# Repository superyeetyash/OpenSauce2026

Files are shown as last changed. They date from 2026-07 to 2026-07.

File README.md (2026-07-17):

# Color Quackdown


An interactive arcade reaction game built for OpenSauce 2026 based on the prompt "Make something interactive." Duck Hunt Reaction Arcade is a modern take on the classic carnival duck shooting game. Instead of shooting ducks, players test their reflexes, accuracy, and color recognition by hitting the correct button before time runs out. The goal was to create a project that could be understood instantly by spectators, encourage repeated play, and combine mechanical design, electronics, and embedded programming into one interactive experience.

## Gameplay

The game uses six mechanical ducks arranged in two rows of three. Each duck is mounted on a servo-powered rack-and-pinion lift that allows it to rise from behind a wall. Every duck has a fixed color. In front of the player are six arcade buttons arranged in the same 2×3 layout, each containing an RGB LED. At the beginning of every round, the button colors are randomized. When a duck rises, the player must identify its color and press the matching illuminated button before the timer reaches zero. If the correct button is pressed, the duck lowers, a success sound plays, the score increases, and the next round begins with less time available. If the wrong button is pressed or time expires, the game ends. The timer progressively decreases after each successful round with a minimum limit of 1.5 seconds.

## Features

The project includes six servo-powered rising duck targets, RGB LED arcade buttons, color recognition gameplay, increasing difficulty, score tracking, high score storage, arcade-style sound effects, a HUB75 RGB LED matrix display, and fully physical controls designed for public interaction at events.

## System Architecture

The Arduino Mega 2560 is the main controller and handles all real-time game functions, including button inputs, RGB LED control, servo movement, game timing, sound effects, and score management. A Raspberry Pi Pico 2 is used as a dedicated display controller for the HUB75 LED matrix. Since HUB75 panels require constant high-speed refreshing, separating the display system from the gameplay controller keeps the game responsive. The Mega communicates with the Pico 2 over UART, sending information such as score, timer values, and game state.

## Bill of Materials (BOM)

| Quantity | Component | Purpose |
|---|---|---|
| 1 | Arduino Mega 2560 | Main game controller handling inputs, outputs, and game logic |
| 1 | Raspberry Pi Pico 2 | Dedicated HUB75 LED matrix display controller |
| 1 | P5 HUB75 64×32 RGB LED Matrix | Main arcade display for score, timer, and animations |
| 6 | MG90S metal gear micro servos | Drives the duck rack-and-pinion lifting mechanisms |
| 6 | 4-pin arcade buttons | Player input controls |
| 6 | Common cathode RGB LEDs | Button lighting system |
| 18 | 220Ω resistors | Current limiting for RGB LED channels |
| 1 | Passive speaker or buzzer | Arcade sound effects |
| 1 | 5V 10A power supply | Powers servos, LED matrix, and electronics |
| 1 | Power distribution block | Splits 5V power between system components |
| 1 | 470–1000µF electrolytic capacitor | Reduces servo voltage spikes |
| 1 | Servo wiring harness or jumper wires | Connects servo power and signals |
| 1 | Assorted jumper wires | General electrical connections |
| 1 | Breadboard or custom PCB | Prototyping and connecting electronics |
| 1 | 3D printed duck assemblies | Physical duck targets |
| 6 | Rack-and-pinion lift assemblies | Converts servo rotation into vertical duck movement |
| 1 | Laser-cut or fabricated enclosure | Houses the arcade system |

## Pin Configuration

The RGB LEDs use a common cathode configuration, with the common pin connected to ground and each RGB channel connected to the Arduino Mega through a 220Ω resistor. The arcade buttons use one signal connection and one ground connection with `INPUT_PULLUP`, meaning a pressed button reads as LOW. The current pin assignments are: pins 2–13 for RGB channels, pins 22–27 for additional RGB channels, pins 28–33 for buttons, and pin 34 for the speaker. The complete pin configuration is stored at the top of `ColorMatchGame/ColorMatchGame.ino`.

## Power System

The servos and HUB75 display should not be powered directly from the Arduino Mega's 5V pin. A dedicated 5V power supply is used to power the system through a distribution block, with separate rails for the servo system and LED matrix. The Arduino Mega, Raspberry Pi Pico 2, servo power, and display power all share a common ground. A 470–1000µF capacitor is placed near the servo power rail to reduce voltage drops caused by servo startup current spikes.

Estimated power requirements:

| Component | Estimated Current |
|---|---|
| Arduino Mega 2560 | ~200mA |
| Six MG90S servos | Up to 2A+ during movement |
| HUB75 LED matrix | 2–3A depending on brightness |
| RGB LEDs and logic | ~300mA |

## Repository Structure

The repository contains the main Arduino firmware in `ColorMatchGame/ColorMatchGame.ino` and the mechanical CAD files in the `cad/` folder. The firmware contains the complete game logic, button handling, RGB control, servo control, timing system, sound effects, and EEPROM high score storage. The CAD files include the duck models, rack-and-pinion lift system, servo mounts, and housing components. The mechanical design is created using parametric OpenSCAD models, allowing dimensions to be modified easily.

## Running the Game

To run the game, open `ColorMatchGame/ColorMatchGame.ino` in the Arduino IDE, select the Arduino Mega or Mega 2560 board, upload the sketch, and open the Serial Monitor at 9600 baud. The firmware includes testing tools that can be accessed through Serial commands, including `t` for RGB LED testing and `c` for button calibration. During startup, the system checks for common wiring issues such as stuck buttons and incorrect LED connections.

## Mechanical Design

Each duck uses a servo-powered rack-and-pinion lift mechanism. A servo rotates a gear, which moves a rack vertically and raises the duck above the wall. The design includes approximately 120mm of vertical travel, 180° servo movement, six identical lift modules, 3D printed ducks, and laser-cut housing panels.

## Development Roadmap

Completed features include the RGB button color matching system, reaction game logic, sound effects, servo-controlled duck movement, rack-and-pinion CAD design, high score storage, HUB75 display support, and Mega-to-Pico UART communication.

## Project Goal

The goal of Duck Hunt Reaction Arcade was to create an arcade experience that requires no explanation. A spectator should immediately understand that a duck appears, a button lights up, the correct button must be pressed, and the score increases. The project combines mechanical engineering, electronics, embedded programming, and game design into a single interactive installation built for OpenSauce 2026.
## Pictures






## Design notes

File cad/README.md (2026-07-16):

# Duck Hunt CAD

Parametric OpenSCAD models for the duck lift mechanism and the laser-cut
housing. **Every shared dimension lives in `params.scad`** — change it there
and all parts update together.

| File | Part | Make | Qty |
|---|---|---|---|
| `duck.scad` | Duck silhouette (~150 mm) | 3D print | 6 |
| `rack_pinion.scad` | Pinion gear / toothed rack | 3D print | 6 + 6 |
| `lift_module.scad` | Servo lift carriage | 3D print | 6 |
| `housing.scad` | Cabinet panels (2D) | Laser cut | see file |

Preview renders are in `preview/`.

## How the mechanism works

The SG90's horn carries a **module-2, 38-tooth pinion** (pitch Ø76 mm).
180° of servo sweep rolls **π × 38 mm ≈ 119 mm of rack travel** — that's the
duck's pop-up height, in ~0.3–0.5 s.

The rack slides vertically in the lift module's C-channel and rises **up
through the module**. The duck hangs off the **bottom** of the rack on a
bridge plate that is raised above the channel wall, so the bridge (and the
duck in front of it) glide past the module's guides for the whole stroke.
Gear separating force presses the rack into the channel wall, so the guide
stays engaged under load.

The lift module screws to a laser-cut mount wall through its 4 corner
holes; the servo drops in from the front, its body passing through both the
printed plate and the matching window in the wall behind it.

## ⚠ Torque budget (read before making ducks heavier)

An SG90 stalls at ~1.8 kg·cm. At the 38 mm pitch radius that is ~470 gf at
the rack — realistically **~200 g of usable lift**. So:

- Print ducks at **10–15% infill, 2 walls** (a 150 mm duck lands ~50–70 g).
- Use **MG90S** (metal gear, identical footprint) if you can — SG90 nylon
  gears strip when a duck gets slapped.
- If lifting is marginal: shrink `pinion_teeth` (e.g. 30 → Ø60 mm, ~94 mm
  travel, 27% more force) — everything re-derives automatically.

## Rendering / exporting

GUI: open a `.scad`, set `part = "..."` at the top, F6, then File → Export.

CLI (OpenSCAD isn't on PATH — use the full path; `openscad.com` prints
console output, `.exe` is silent):

```powershell
$scad = "C:\Program Files\OpenSCAD\openscad.com"
cd cad
& $scad -o duck.stl duck.scad
& $scad -o pinion.stl -D 'part="pinion"' rack_pinion.scad
& $scad -o rack.stl   -D 'part="rack"'   rack_pinion.scad
& $scad -o lift_module.stl -D 'part="module"' lift_module.scad
# housing panels, one DXF per part for the laser:
foreach ($p in "front","back","side","base","mount","deck") {
  & $scad -o "$p.dxf" -D "part=`"$p`"" housing.scad
}
```

Sanity previews: `part="mesh"` in `rack_pinion.scad` shows the gear
engagement; `part="assembly"` in `lift_module.scad` shows the whole lift;
`part="layout"` in `housing.scad` shows all panels labeled (preview only —
**don't cut the layout sheet**, the labels are text outlines).

## Print settings

| Part | Orientation | Infill | Supports |
|---|---|---|---|
| Duck | Flat on its side | 10–15%, 2 walls | No |
| Pinion | Horn pocket down | 25% | No |
| Rack | Teeth flat, back face down | 25% | Only under the bridge wings |
| Lift module | Back plate down | 20% | No (lip is 45° chamfered) |

PETG or PLA both fine. A drop of dry PTFE lube in the channel helps.

## Assembly (one lift, ×6)

1. Screw a cross/2-arm horn into the pinion's back pocket (M2 self-tappers
   through the 4 holes; the center channel gives screwdriver access).
2. Drop the servo into the module from the front, body through the window;
   screw the tabs to the plate.
3. Slide the rack into the channel, teeth toward the servo axis.
4. With the servo at 0°, hold the rack at "duck hidden" height and press
   the pinion+horn onto the servo spline, meshing the teeth; fit the horn
   screw. (This sets the travel phase — no code calibration needed.)
5. Bolt a duck to the bridge plate: 2× M3 from behind.
6. Screw the module to the mount wall; the wall's servo window must line up
   (both come from the same `params.scad`, so they do).

## Housing notes

- Panels assume **6 mm stock** (`mat_t`); tabs/slots derive from it, and
  `laser_kerf` (default 0.15) makes joints snug — set it for your machine,
  or 0 if your laser software compensates kerf.
- Biggest panels are 540 × 300 mm (+ 6 mm tabs) — needs a ~600 × 400 bed.
- The two mount walls are identical; they tab into the base at
  `mount_wall_d1/d2` and should get corner brackets or hot glue to the
  sides for stiffness.
- `button_hole_d` is a guess (12 mm) — **measure your actual buttons/caps**
  before cutting the deck.
- Rack tips rise above the mount walls at full pop — the 300 mm back wall
  covers them from the audience.

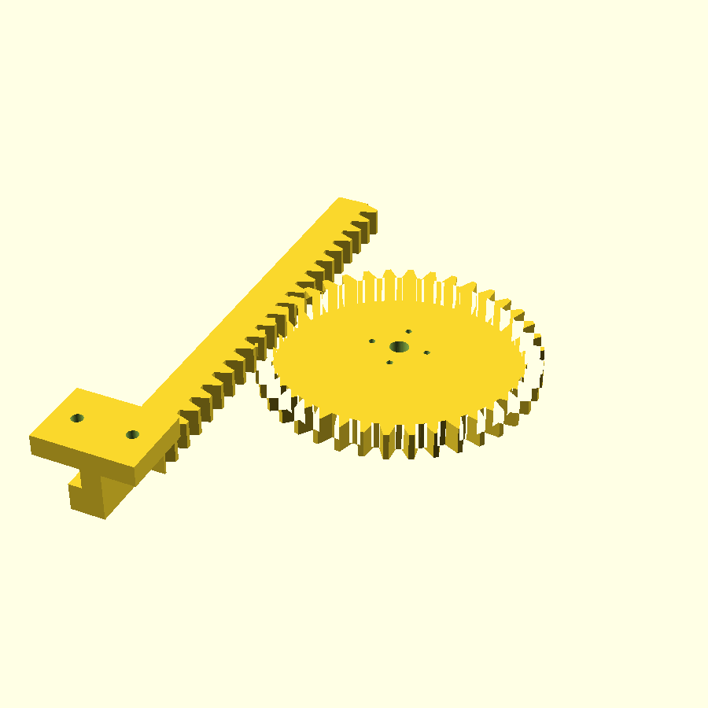
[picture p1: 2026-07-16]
cad/preview/mesh.png

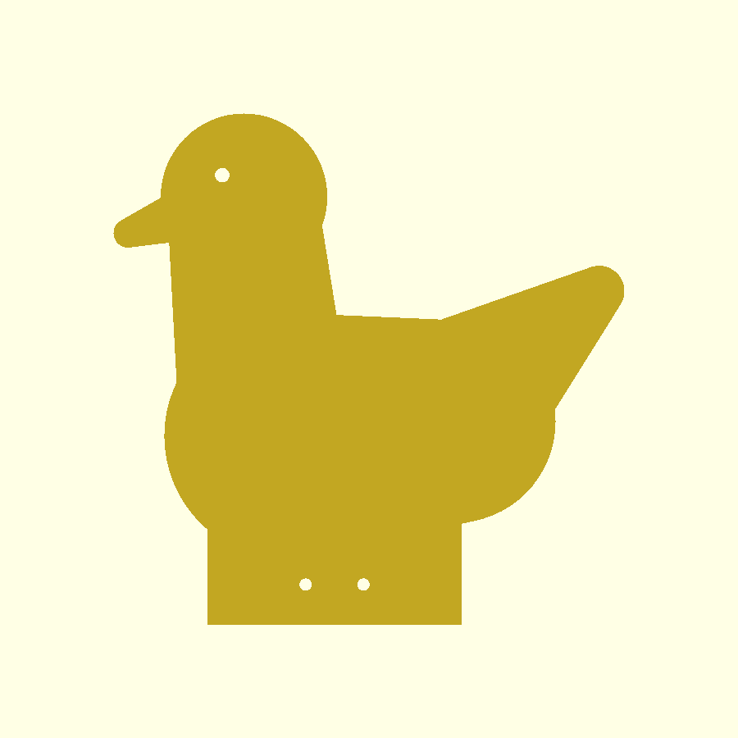
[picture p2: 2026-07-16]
cad/preview/duck.png

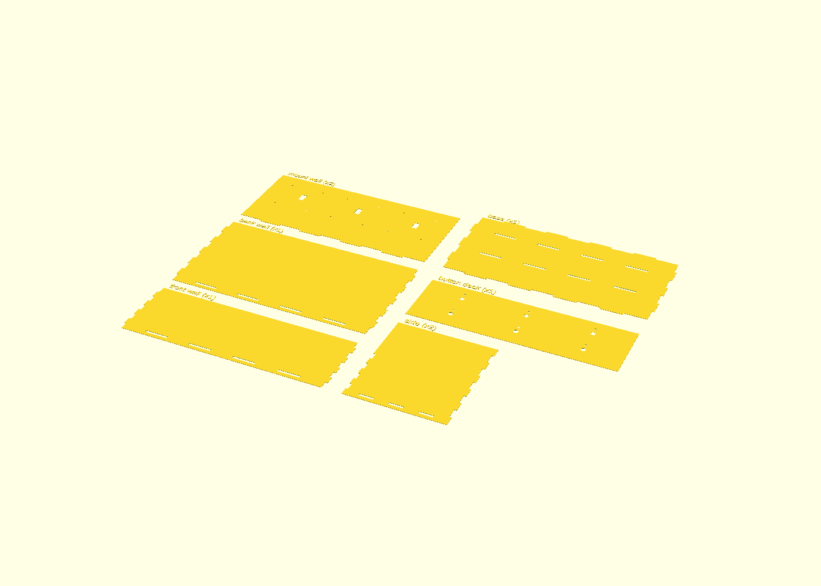
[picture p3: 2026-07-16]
cad/preview/layout.png

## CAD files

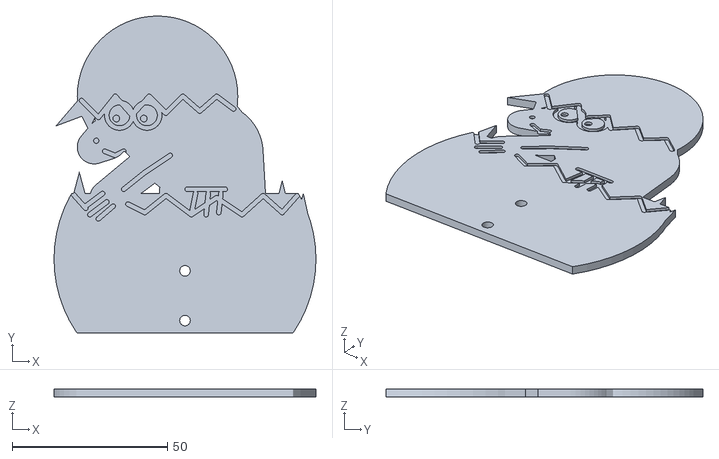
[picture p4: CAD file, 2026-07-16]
cad/orpheus_thin.stl
84.3 x 102.0 x 2.50

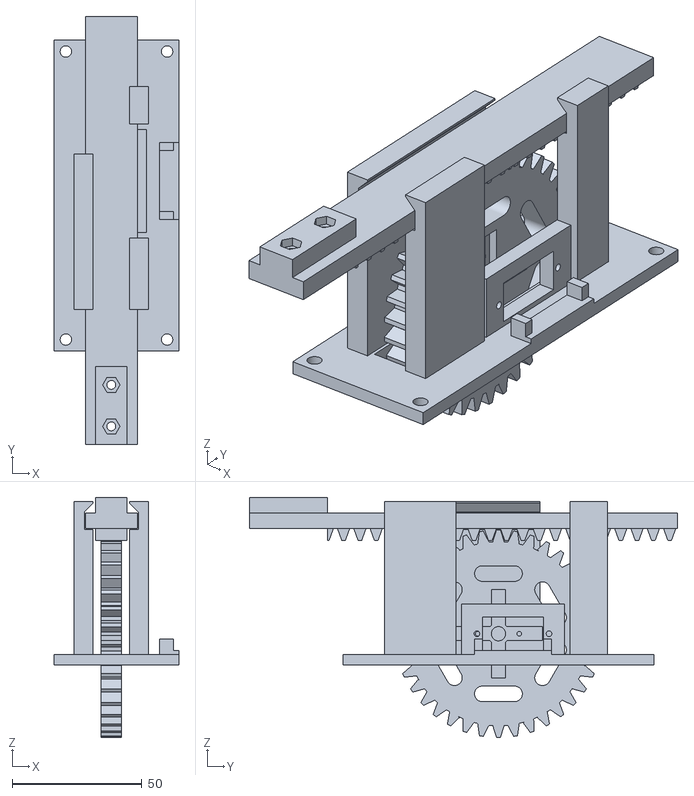
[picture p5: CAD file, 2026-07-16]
cad/lift_module.stl
48.0 x 165.0 x 92.5

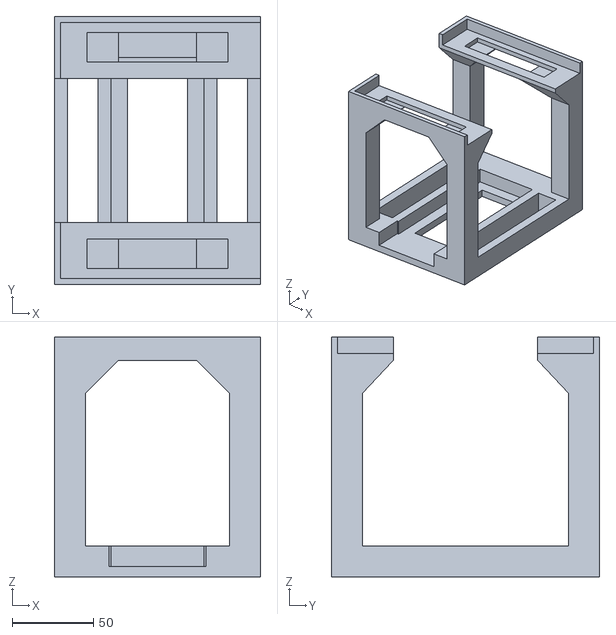
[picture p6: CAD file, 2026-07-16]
cad/arduino_box2.stl
127.0 x 165.1 x 147.6

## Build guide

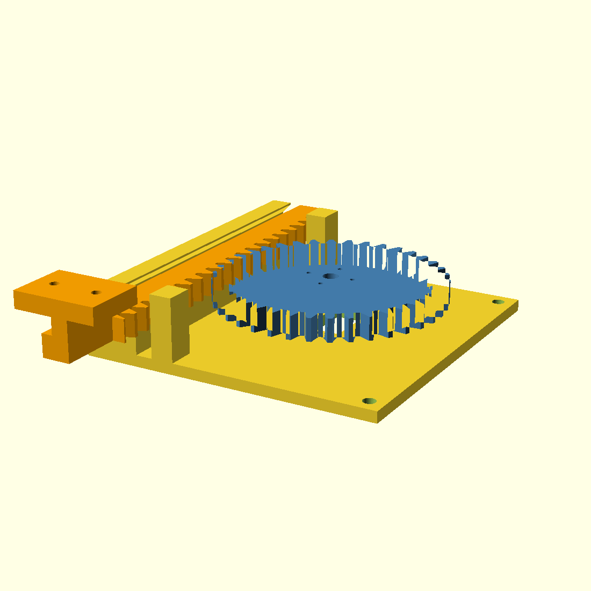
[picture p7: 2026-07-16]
cad/preview/assembly.png

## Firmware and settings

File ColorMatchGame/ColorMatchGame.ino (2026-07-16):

#include <Wire.h>
#include <LiquidCrystal_I2C.h>
#include <Servo.h>


// ================= LCD =================

LiquidCrystal_I2C lcd(0x27,16,2);


// ================= COLORS =================

enum Color {
  RED,
  PURPLE,
  GREEN,
  BLUE
};


String colorNames[4] = {
  "RED",
  "PURPLE",
  "GREEN",
  "BLUE"
};


// Fixed duck colors

Color duckColors[4] = {
  RED,
  PURPLE,
  GREEN,
  BLUE
};


// ================= RGB LED PINS =================

int redPins[4] = {
  2,5,8,11
};

int greenPins[4] = {
  3,6,9,12
};

int bluePins[4] = {
  4,7,10,13
};


// ================= BUTTON PINS =================

int buttonPins[4] = {
  22,23,24,25
};


// ================= SERVOS =================

Servo ducks[4];


int servoPins[4] = {
  26,27,28,29
};


int duckDown = 0;
int duckUp = 90;


// ================= BUTTON COLORS =================

Color buttonColors[4];


// ================= GAME VARIABLES =================

int activeDuck;

int score = 0;


bool roundActive = false;


unsigned long roundStart;


int roundTime = 10;


unsigned long lastPress[4];

int debounceDelay = 150;



// ================= SETUP =================


void setup(){


  Serial.begin(9600);


  randomSeed(
    analogRead(A0)
  );


  // LCD

  lcd.init();

  lcd.backlight();


  lcd.clear();

  lcd.setCursor(0,0);

  lcd.print("DUCK HUNT");


  lcd.setCursor(0,1);

  lcd.print("Starting...");


  delay(2000);



  // RGB

  for(int i=0;i<4;i++){

    pinMode(redPins[i],OUTPUT);
    pinMode(greenPins[i],OUTPUT);
    pinMode(bluePins[i],OUTPUT);

  }



  // Buttons

  for(int i=0;i<4;i++){

    pinMode(
      buttonPins[i],
      INPUT_PULLUP
    );


    lastPress[i]=0;

  }



  // Servos

  for(int i=0;i<4;i++){

    ducks[i].attach(
      servoPins[i]
    );


    ducks[i].write(
      duckDown
    );

  }



  startRound();


}




// ================= LOOP =================


void loop(){


  updateTimer();

  checkButtons();


}




// ================= START ROUND =================


void startRound(){


  clearLEDs();


  activeDuck =
  random(0,4);



  Serial.println("================");

  Serial.println("NEW ROUND");


  Serial.print("Duck Activated: ");

  Serial.println(
    activeDuck+1
  );


  Serial.print("Duck Color: ");

  Serial.println(
    colorNames[
      duckColors[activeDuck]
    ]
  );



  // Duck rises FIRST

  ducks[activeDuck].write(
    duckUp
  );



  delay(700);



  randomizeButtons();



  roundStart = millis();


  roundActive=true;



}



// ================= TIMER =================


void updateTimer(){


  if(!roundActive)
    return;



  int remaining =
  roundTime -
  ((millis()-roundStart)/1000);



  lcd.setCursor(0,0);

  lcd.print("Score:");

  lcd.print(score);

  lcd.print(" ");



  lcd.setCursor(9,0);

  lcd.print("T:");

  lcd.print(remaining);

  lcd.print(" ");



  lcd.setCursor(0,1);

  lcd.print("Duck:");

  lcd.print(
    colorNames[
      duckColors[activeDuck]
    ]
  );



  if(remaining<=0){

    loseRound();

  }
  

}
// ================= BUTTON INPUT =================


void checkButtons(){


  if(!roundActive)
    return;



  for(int i=0;i<4;i++){


    if(
      digitalRead(buttonPins[i])
      ==LOW
    ){


      if(
        millis()-lastPress[i]
        >debounceDelay
      ){


        lastPress[i]=millis();


        buttonPressed(i);


      }


    }


  }


}




void buttonPressed(int button){


  Serial.println();


  Serial.print("Pressed Button: ");

  Serial.println(button+1);



  Serial.print("Button Color: ");

  Serial.println(
    colorNames[
      buttonColors[button]
    ]
  );



  if(
    buttonColors[button]
    ==
    duckColors[activeDuck]
  ){

    correctRound();

  }

  else{


    wrongButton();


  }



}



// ================= CORRECT =================


void correctRound(){


  roundActive=false;


  Serial.println("CORRECT");


  Serial.print("Lowering Duck: ");

  Serial.println(
    activeDuck+1
  );



  ducks[activeDuck].write(
    duckDown
  );


  score++;



  lcd.clear();


  lcd.setCursor(0,0);

  lcd.print("CORRECT!");


  lcd.setCursor(0,1);

  lcd.print("Score:");

  lcd.print(score);



  flashColor(GREEN);



  delay(1200);



  startRound();


}




// ================= WRONG =================


void wrongButton(){


  Serial.println("WRONG BUTTON");


  lcd.clear();


  lcd.setCursor(0,0);

  lcd.print("WRONG");


  lcd.setCursor(0,1);

  lcd.print("TRY AGAIN");



  // Flash red feedback

  for(int i=0;i<4;i++){

    setLED(
      i,
      RED
    );

  }


  delay(300);



  // Restore original button colors

  for(int i=0;i<4;i++){

    setLED(
      i,
      buttonColors[i]
    );

  }


}





// ================= TIME LOSS =================


void loseRound(){


  roundActive=false;



  ducks[activeDuck].write(
    duckDown
  );



  Serial.println("TIME UP");



  lcd.clear();


  lcd.setCursor(0,0);

  lcd.print("TIME UP!");


  lcd.setCursor(0,1);

  lcd.print("Score:");

  lcd.print(score);



  flashColor(RED);



  delay(2000);



  startRound();


}




// ================= RANDOM RGB =================


void randomizeButtons(){


  Color temp[4]={

    RED,
    PURPLE,
    GREEN,
    BLUE

  };



  for(int i=0;i<4;i++){


    int r=random(0,4);


    Color swap=temp[i];

    temp[i]=temp[r];

    temp[r]=swap;


  }



  for(int i=0;i<4;i++){


    buttonColors[i]=temp[i];


    setLED(
      i,
      buttonColors[i]
    );



    Serial.print("Button ");

    Serial.print(i+1);

    Serial.print(": ");

    Serial.println(
      colorNames[
        buttonColors[i]
      ]
    );


  }


}



// ================= RGB CONTROL =================


void setLED(
int led,
Color c
){


  int r=0;

  int g=0;

  int b=0;



  switch(c){


    case RED:

      r=255;

      break;


    case PURPLE:

      r=255;

      b=255;

      break;


    case GREEN:

      g=255;

      break;


    case BLUE:

      b=255;

      break;


  }



  analogWrite(
    redPins[led],
    r
  );


  analogWrite(
    greenPins[led],
    g
  );


  analogWrite(
    bluePins[led],
    b
  );


}




void clearLEDs(){


  for(int i=0;i<4;i++){


    analogWrite(
      redPins[i],
      0
    );


    analogWrite(
      greenPins[i],
      0
    );


    analogWrite(
      bluePins[i],
      0
    );


  }


}




void flashColor(Color c){


  for(int i=0;i<4;i++){

    setLED(
      i,
      c
    );

  }


  delay(300);


  clearLEDs();


}

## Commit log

2026-07-16 Add Duck Hunt docs, round timer + speaker, and CAD models
    - README: full project docs (gameplay, BOM, pin map, power plan, roadmap)
    - CLAUDE.md: dev conventions and Mega timer budget
    - ColorMatchGame build 4: shrinking round timer (8s, halves per round,
    1.5s floor) with countdown, and non-blocking speaker sounds on pin 34
    - cad/: parametric OpenSCAD for duck, rack & pinion (module 2, 38T,
    ~119mm travel per 180deg), servo lift module, and laser-cut housing
    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
    [duck.scad, housing.scad, lift_module.scad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]
2026-07-16 updated cad models
    [arduino_box2.stl, duck.scad, housing.scad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]
